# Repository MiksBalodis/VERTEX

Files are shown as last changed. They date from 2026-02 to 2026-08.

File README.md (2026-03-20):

# Aktīvās kontroles raķetes avionikas sistēma

## Projekta apraksts
Šis projekts paredz aktīvās kontroles raķetes avionikas sistēmas izstrādi, kas ietver gan raķetē iebūvētu avionikas datoru, gan zemes bāzi datu saņemšanai, uzglabāšanai un analīzei. Sistēma nodrošina aktīvu trajektorijas korekciju reāllaikā, izmantojot sensoru datus, vadības algoritmus un elektroniskos izpildmehānismus.

Projektā tiek apvienotas iegultās sistēmas, signālu apstrāde, vadības algoritmi, telemetrija un lietotāja saskarnes izstrāde.

**Projektu izstrādā:**  
Aleksandrs Jesiļevskis  
Miks Balodis  

---

## Projekta mērķis
Izstrādāt:
- raķetes avionikas datoru ar aktīvas trajektorijas korekcijas iespējām,
- zemes bāzi lidojuma datu saņemšanai un analīzei,
- drošu un papildināmu sistēmu, kas piemērota eksperimentālām lieljaudas raķetēm.

Sistēmai jāspēj:
- reāllaikā noteikt raķetes stāvokli,
- veikt aktīvo vadību ar vairākām kontroles spurām,
- ierakstīt un uzglabāt lidojuma datus,
- nodrošināt saziņu ar zemes bāzi lidojuma laikā.

---

## Idejas rašanās
Ideja radās, balstoties uz **RTU Lieljaudas raķeškomandas (RTU HPR)** 2025. gada 1. semestra projektu – aktīvās rotācijas kontroles raķeti. Šī projekta ietvaros tika izmantots RP2040 mikrokontrolieris, kuram konstatēti vairāki ierobežojumi:
- nav iebūvēta peldošā komata vienības (FPU),
- ierobežota programmas atmiņa,
- augsts enerģijas patēriņš.

Lai šos trūkumus novērstu, projektā tiek izvēlēts **STM32F405RGT6**, kas nodrošina augstāku veiktspēju, FPU atbalstu un DSP instrukcijas.

---

## Idejas apraksts

### Projekta lietotāji
- studentu raķešu komandas,
- augstskolu/vidusskolu eksperimentēšanas grupas,
- iegulto sistēmu un vadības algoritmu izstrādātāji,
- eksperimentālu raķešu un bezpilota sistēmu entuziasti.

### Izmantotās tehnoloģijas
- **Iegultās sistēmas:** STM32 (ARM Cortex-M4)
- **Sensori:** barometrs, IMU, GNSS
- **Vadības algoritmi:** PID, Kalmana filtrs
- **Telemetrija:** sub-GHz radio sakari
- **Programmatūra:** C/C++, MatLab/Simulink (simulācijas), JavaScript un Svelte (GUI)
- **Projektēšana:** KiCad

### Piegādes formāts
Projekta rezultāts būs:
- raķetes avionikas sistēmas plate (PCB),
- iegultā programmatūra gatava demonstratīvam raķetes lidojumam (firmware),
- zemes bāzes programmatūra (GUI),
- dokumentācija.

Šāda pieeja ļauj sistēmu izmantot gan eksperimentālos lidojumos, gan simulācijās.

---

## Aktīvā kontrole
Aktīvā kontrole ir vadības sistēma, kas lidojuma laikā nepārtraukti:
- mēra raķetes stāvokli (leņķi, ātrumu, rotāciju),
- aprēķina nepieciešamos labojumus,
- ģenerē PWM signālus izpildmehānismiem servo kontrolētām spurām.

Sistēma atbalsta līdz **4 aktīvām spurām**, katrai paredzot atsevišķu PWM kanālu. Salīdzinājumā ar pasīvo kontroli, aktīvā kontrole spēj reaģēt uz ārējiem traucējumiem un uzlabot stabilitāti un precizitāti.

---

## Risinājuma arhitektūra

### Konceptuālais modelis
Sistēma sastāv no trim galvenajiem blokiem:
1. **Sensoru slānis** – datu iegūšana
2. **Vadības un apstrādes slānis** – aprēķini un lēmumu pieņemšana
3. **Izpildes un komunikācijas slānis** – kontrole, datu uzglabāšana un pārraide

### Tehniskā arhitektūra

#### MCU
- **STM32F405RGT6** - mikrokontrolieris datu apstrādei un komandu nodošanai

#### Sensori
- **BMP388** – barometrs augstuma noteikšanai
- **LSM6DSO** – IMU (akselerometrs + žiroskops)
- **MAX-M10S** – GNSS modulis augstas precizitātes pozīcijai

#### Datu uzglabāšana
- **MXL1606** – lidojuma datu ierakstīšanai (USB Mass Storage režīms)
- **24LC64 EEPROM** – konfigurācijas datiem

#### Telemetrija
- **EBYTE E22-400M22S** - LoRa moudlis saziņai ar zemes bāzi (433 MHz)

#### Vadība
- PWM signāli spuru servo
- PID regulators
- Kalmana filtrs stāvokļa novērtēšanai

Projekta izstrādes Gantt diagramma
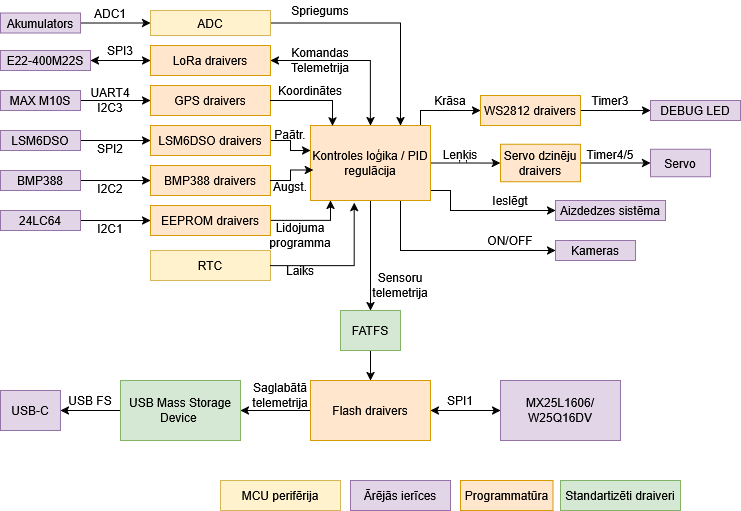
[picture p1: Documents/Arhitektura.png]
Projekta izstrādes Gantt diagramma

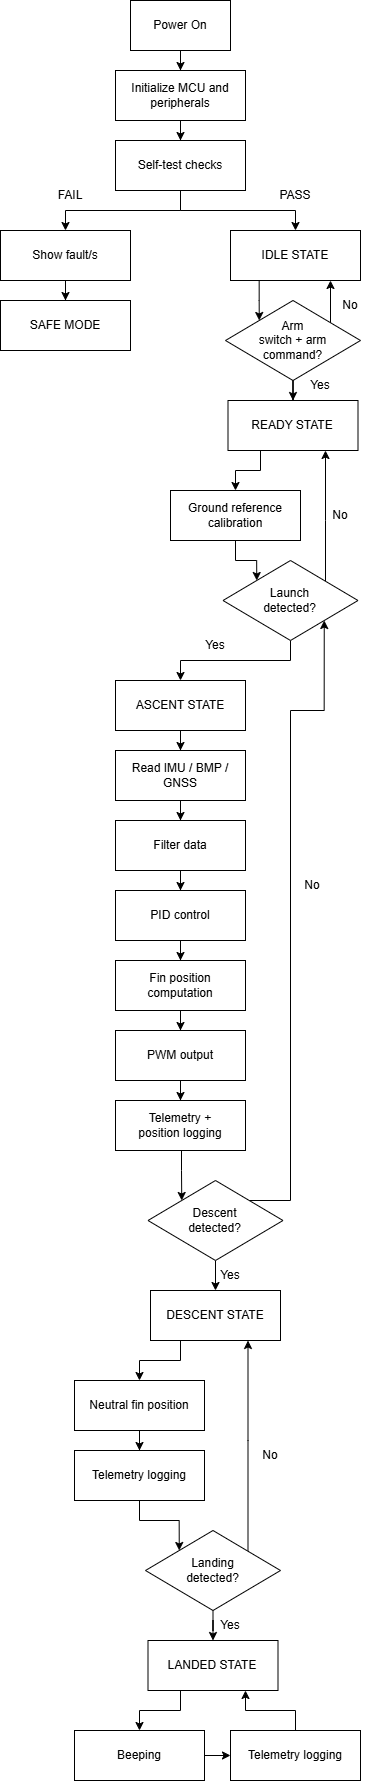
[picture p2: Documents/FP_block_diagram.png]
Flight computer block diagram


---
## Izstrādes plāns (10 nedēļas)

Projekta izstrāde ir plānota 10 nedēļu laikā, pieņemot, ka avionikas plate jau ir uzdizainēta un pasūtīta, un nākamais solis ir tās salodēšana. Darbs tiek sadalīts starp diviem izstrādātājiem, lai maksimāli efektīvi izmantotu paralēlu izstrādi.

### Lomu sadalījums
- **Aleksandrs** – iegultās sistēmas programmēšana, STM32 firmware, sensoru draiveri, datu plūsma, vadība un telemetrija, sistēmas arhitektūras lēmumi,  integrācija, testēšana un dokumentācija.
- **Miks** – raķetes tehniskā daļa, mehāniskā integrācija, Matlab/Simulink simulācijas, vadības algoritmu modelēšana un zemes stacijas aparatūra, sistēmas arhitektūras lēmumi,  integrācija, testēšana un dokumentācija.

---

### 1. nedēļa – Sistēmas inicializācija un modeļu sagatavošana
**Aleksandrs:**
- STM32CubeIDE projekta izveide
- Pulksteņu (clock tree) un pamata perifēriju konfigurācija
- Debug interfeisa (SWD/UART) inicializācija

**Miks:**
- Raķetes kustības konceptuālā modeļa izstrāde
- Aktīvās kontroles uzdevuma definēšana
- Sensoru mērījumu teorētisko modeļu izveide

**Rezultāts:**  
MCU veiksmīgi startē un sistēmas matemātiskais modelis ir definēts.

---

### 2. nedēļa – Perifēriju un datu plūsmas pamati
**Aleksandrs:**
- GPIO, UART, SPI un I2C konfigurācija
- DMA izmantošanas pamati datu pārsūtīšanai
- Vienkārša datu izvada testēšana

**Miks:**
- PID regulatora struktūras izveide Matlab/Simulink
- Sākotnējo vadības parametru novērtēšana
- Avionikas plates salodēšana

**Rezultāts:**  
MCU spēj komunicēt ar perifērijām, un PID struktūra ir gatava simulācijām, plate ir salodēta.

---

### 3. nedēļa – Avionikas plates salodēšana un sensoru testēšana
**Aleksandrs:**
- IMU (LSM6DSO) un barometra (BMP388) draiveru izstrāde
- Sensoru datu nolasīšana un izvadīšana caur UART

**Miks:**
- Barošanas un signālu līmeņu pārbaude
- Sensoru fiziskās integrācijas novērtēšana

**Rezultāts:**  
Pilnībā funkcionējoši aktīvie sensori.

---

### 4. nedēļa – GNSS un sensoru apvienošana
**Aleksandrs:**
- GNSS (MAX-M10S) draivera izstrāde
- Laika sinhronizācija starp sensoriem
- Datu struktūru definēšana

**Miks:**
- Sensoru kalibrācijas metodes
- Kļūdu modelēšana
- Mērījumu precizitātes izvērtēšana

**Rezultāts:**  
Apvienoti visi sensoru dati vienotā laika skalā.

---

### 5. nedēļa – Aktīvā vadība un izpildmehānismi
**Aleksandrs:**
- PWM izvades konfigurācija
- Taimeru konfigurācija izpildmehānismiem
- Izpildmehānismu testēšana

**Miks:**
- PID parametru regulēšana Simulink vidē
- Stabilitātes analīze
- Vadības algoritma validācija simulācijā

**Rezultāts:**  
Izpildmehānismi reaģē uz vadības signāliem paredzētajā veidā.

---

### 6. nedēļa – Datu apstrāde un uzglabāšana
**Aleksandrs:**
- USB Mass Storage režīma ieviešana
- Datu struktūras optimizācija

**Miks:**
- Kalmana filtra izstrāde Simulink vidē
- Algoritma sagatavošana ieviešanai C kodā

**Rezultāts:**  
Stabili ierakstīti un izgūstami lidojuma dati.

---

### 7. nedēļa – Telemetrija un zemes stacijas aparatūra
**Aleksandrs:**
- Telemetrijas protokola izstrāde
- EBYTE E22 radio moduļa integrācija
- Datu pakešu formāta definēšana

**Miks:**
- Zemes stacijas plates arhitektūras izstrāde
- Komponentu izvēle un shēmas dizains
- Komunikācijas interfeisa plānošana

**Rezultāts:**  
Bezvadu datu pārraide starp raķeti un zemes staciju.

---

### 8. nedēļa – Zemes stacijas programmatūra un GUI
**Aleksandrs:**
- Seriālās komunikācijas protokols ar datoru
- Telemetrijas datu parsēšana

**Miks:**
- Grafiskās lietotāja saskarnes izstrāde (Svelte)
- Reāllaika grafiki un datu attēlošana
- Datu eksportēšana analīzei

**Rezultāts:**  
Darbojoša zemes stacija ar reāllaika datu vizualizāciju.

---

### 9. nedēļa – Integrācija un sistēmas testi
**Aleksandrs:**
- Pilna vadības cikla integrācija
- Kļūdu apstrāde un drošības mehānismi

**Miks:**
- Vibrāciju testi
- Sensoru trokšņu ietekmes pārbaude

**Rezultāts:**  
Stabila un integrēta sistēma bez kritiskām kļūdām.

---

### 10. nedēļa – Stabilizācija un dokumentācija
**Abi:**
- Koda un aparatūras kļūdu labošana
- Projekta dokumentācijas pabeigšana
- Demonstrācijas sagatavošana

**Rezultāts:**  
Pilnībā sagatavots projekts demonstrācijai un prezentācijai.

---

## Projekta izstrādes grafiks

Projekta izstrādes Gantt diagramma

---

## Licence
Licence tiks noteikta projekta vēlākā izstrādes posmā.

---

## Kontakti
Jautājumu vai sadarbības gadījumā sazināties ar projekta izstrādātājiem.

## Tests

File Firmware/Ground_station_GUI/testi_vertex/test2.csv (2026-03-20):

time_ms | state | pitch | yaw | roll | altitude | speed | acceleration | error_flags | status_text
0 | IDLE | 0 | 0 | 0 | 0 | 0 | 0 | NONE | Systems safe. Awaiting command.
90 | IDLE | 0 | 0 | 0 | 0 | 0 | 0 | NONE | Systems safe. Awaiting command.
180 | IDLE | 0 | 0 | 0 | 0 | 0 | 0 | NONE | Systems safe. Awaiting command.
270 | IDLE | 0 | 0 | 0 | 0 | 0 | 0 | NONE | Systems safe. Awaiting command.
360 | IDLE | 0 | 0 | 0 | 0 | 0 | 0 | NONE | Systems safe. Awaiting command.
450 | IDLE | 0 | 0 | 0 | 0 | 0 | 0 | NONE | Systems safe. Awaiting command.
540 | IDLE | 0 | 0 | 0 | 0 | 0 | 0 | NONE | Systems safe. Awaiting command.
630 | IDLE | 0 | 0 | 0 | 0 | 0 | 0 | NONE | Systems safe. Awaiting command.
720 | IDLE | 0 | 0 | 0 | 0 | 0 | 0 | NONE | Systems safe. Awaiting command.
810 | IDLE | 0 | 0 | 0 | 0 | 0 | 0 | NONE | Systems safe. Awaiting command.
900 | SAFE | 0 | 0 | 0 | 0 | 0 | 0 | SELF_TEST_FAIL|IMU_FAIL | System fault detected. Safe mode active.
960 | SAFE | 0 | 0 | 0 | 0 | 0 | 0 | SELF_TEST_FAIL|IMU_FAIL | System fault detected. Safe mode active.
1020 | SAFE | 0 | 0 | 0 | 0 | 0 | 0 | SELF_TEST_FAIL|IMU_FAIL | System fault detected. Safe mode active.
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

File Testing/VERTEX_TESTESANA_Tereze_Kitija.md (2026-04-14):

# VERTEX projekta testēšana

RTU Inženierzinātņu vidusskolas  
11. klases skolnieces  
**Kitija Kampiņa** un **Terēze Luīze Kīne**  

---

# Funkcionālie testi

| Testa veids | Ievade, darbība | Sagaidāmais rezultāts | Patiesais rezultāts |
|---|---|---|---|
| CSV failu ielāde un testu palaišana | CSV failu ielāde un testu palaišana | CSV faili tiek veiksmīgi ielādēti un tests tiek palaists. | Strādā. CSV faili ielādējas un testēšana sākas. |
| Testu atkārtošana | Jauna vai tā paša CSV faila ielāde un atkārtota testēšana | Iespējams ielādēt jaunu failu un atkārtoti palaist testu ar to pašu vai citu CSV. | Daļēji strādā. Jaunu failu var ielādēt, bet atkārtota tā paša faila testēšana nedarbojas. Noderētu "Refresh" funkcija. |
| Normāls pilns lidojums | Pilna lidojuma scenārija simulācija | Stāvokļi mainās secīgi (IDLE → READY → ASCENT → DESCENT → LANDED), bez kļūdām rādījumi pieaug un pēc nosēšanās atgriežas uz nulli. | Strādā. Tiek veiksmīgi pārslēgti stāvokļi un netiek uzrādīta neviena kļūda. |
| Kļūda pirms lidojuma / SAFE režīms | Kļūdas aktivizēšana pirms lidojuma | Sistēma pāriet SAFE režīmā, lidojums nesākas, dati neizmainās. | Strādā. tiek uzrādītas SELF_TEST_FAIL un IMU_FAIL kļūdas. |
| Neatļauta stāvokļu pāreja | Nepareizas stāvokļu secības izsaukšana | Sistēma atpazīst nepareizu secību un uzrāda kļūdu. | Strādā. INVALID_STATE_TRANSITION kļūda tiek uzrādīta. |
| IMU datu zudums un atkopšanās | IMU datu zuduma simulācija | Parādās īslaicīgs datu zudums, pēc tam sistēma atkopjas, un lidojums beidzas veiksmīgi. | Strādā. IMU_DATA_LOST un IMU_RECOVERED tiek korekti uzrādīti. |
| Vairākas vienlaicīgas kļūdas | Vairāku kļūdu vienlaicīga aktivizēšana | Sistēma apstrādā vairākas kļūdas vienlaikus un turpina darbību. | Strādā. Nolaišanās laikā uzrāda GPS_LOST, BARO_FAIL un LOW_BATTERY kļūdu. Veiksmīga nosēšanās. |
| Sakaru zudums un GPS svārstības | Nestabilas sakaru un GPS darbības simulācija | Sistēma turpina darbību pēc īslaicīgas nestabilitātes. | Strādā. Lidojuma laikā tiek uzrādītas vairākas kļūdas, notiek atkopšanās un veiksmīga nosēšanās. |
| Stāvokļa pārejas kļūda ar atkopšanos | Kļūdas un atkopšanās scenārijs | Sistēma konstatē kļūdu un pēc tam atkopjas. | Strādā. Uzrāda INVALID_STATE_TRANSITION kļūdu, notiek atkopšanās un veiksmīga nosēšanās. |
| Jaukts anomāliju tests | Kombinēts kļūdu scenārijs | Sistēma apstrādā vairākas kļūdas bez darbības pārtraukuma. | Strādā. Lidojuma laikā parādās daudz kļūdas paziņojumu, notiek atkopšanās un veiksmīga nosēšanās. |

---

# Nefunkcionālie testi

| Testa veids | Ievade, darbība | Sagaidāmais rezultāts | Patiesais rezultāts |
|---|---|---|---|
| Atvēršana no citiem datoriem | Sistēmas atvēršana no cita datora tīklā | Sistēma ir pieejama tīklā un darbojas citos datoros. | Strādā. Sistēmu var atvērt no citiem datoriem. |
| Atvēršana no mobilajām ierīcēm | Sistēmas atvēršana mobilajā ierīcē | Sistēma darbojas mobilajās ierīcēs ar pielāgotu UI. | Nestrādā. aplikācija nav optimizēta mobilajām ierīcēm. |
| Sākumlapas pieejamība | Viena HTTP pieprasījuma nosūtīšana | Sistēma atbild uz pieprasījumu bez kļūdām. | Tika nosūtīts viens HTTP pieprasījums, kas tika apstrādāts veiksmīgi (100% OK, 0% kļūdu). Atbildes laiks bija 340 ms, kas norāda uz pieņemamu reakcijas ātrumu. Tomēr, ņemot vērā, ka tests ietvēra tikai vienu pieprasījumu, nav iespējams izdarīt secinājumus par sistēmas veiktspēju vai stabilitāti pie lielākas slodzes. Šis tests kalpo kā sākotnējais sistēmas pieejamības pārbaudījums (smoke test). |
| Vienmērīga lietotāju slodze | 300 HTTP pieprasījumu nosūtīšana | Sistēma uztur stabilu veiktspēju pie nemainīgas slodzes. | Tika nosūtīti 300 HTTP pieprasījumi, no kuriem visi tika apstrādāti veiksmīgi (100% OK, 0% kļūdu). Vidējais atbildes laiks bija 29 ms, savukārt 95% pieprasījumu tika apstrādāti ātrāk par 66 ms, kas norāda uz ļoti labu sistēmas veiktspēju. Lai gan maksimālais atbildes laiks sasniedza 557 ms, šādi gadījumi bija reti un neietekmē kopējo sistēmas darbību. Rezultāti liecina, ka sistēma ir stabila un spēj efektīvi apkalpot lietotājus pie dotās slodzes. |
| Pieaugoša slodze (Ramp-up) | Pakāpeniski pieaugoša pieprasījumu plūsma | Sistēma saglabā veiktspēju pie pakāpeniskas slodzes pieauguma. | Tika simulēts pakāpeniski pieaugošs lietotāju skaits, nosūtot 100 HTTP pieprasījumus 58 sekunžu laikā. Visi pieprasījumi tika apstrādāti veiksmīgi (100% OK, bez kļūdām). Vidējais atbildes laiks bija 18 ms, savukārt 95% pieprasījumu tika apstrādāti ātrāk par 26 ms, kas liecina par ļoti labu sistēmas veiktspēju arī pie pieaugošas slodzes. Maksimālais atbildes laiks sasniedza 175 ms, tomēr šādi gadījumi bija reti un neietekmēja kopējo sistēmas darbību. Rezultāti norāda, ka sistēma spēj stabili un efektīvi apkalpot lietotājus pie pakāpeniski pieaugošas slodzes bez būtiskas veiktspējas degradācijas. |
| Ilgstoša slodze (Soak test) | Ilgstoša slodze ar 1500 pieprasījumiem | Sistēma ilgstoši darbojas bez veiktspējas pasliktināšanās. | Tika simulēta ilgstoša, nemainīga slodze 5 minūšu laikā, nosūtot 1500 HTTP pieprasījumus. Visi pieprasījumi tika apstrādāti veiksmīgi (100% OK, bez kļūdām). Vidējais atbildes laiks bija 14 ms, savukārt 95% pieprasījumu tika apstrādāti ātrāk par 20 ms, kas norāda uz ļoti stabilu sistēmas darbību ilgstošas slodzes apstākļos. Maksimālais atbildes laiks sasniedza 198 ms, tomēr šādi gadījumi bija reti un neietekmēja kopējo sistēmas veiktspēju. Testa rezultāti neuzrādīja būtisku veiktspējas degradāciju laika gaitā, kas liecina par sistēmas stabilitāti un spēju uzturēt nemainīgu darbību ilgstošas slodzes apstākļos. |
| Pīķa slodze (Spike test) | Straujš pieprasījumu pieaugums (200 vienlaikus) | Sistēma saglabā darbību pie strauja slodzes pieauguma. | Pīķa slodzes testā tika simulēts straujš lietotāju skaita pieaugums, vienlaikus nosūtot 200 pieprasījumus. Visi pieprasījumi tika apstrādāti veiksmīgi (100% OK, bez kļūdām), kas liecina par sistēmas stabilitāti pat pie augstas slodzes. Tomēr vidējais atbildes laiks būtiski palielinājās līdz 1115 ms, un lielākā daļa pieprasījumu tika apstrādāti 800–1200 ms intervālā. Tas norāda, ka sistēma nespēj uzturēt augstu veiktspēju pie pēkšņas slodzes pieauguma, lai gan tā saglabā funkcionalitāti. Rezultāti liecina, ka sistēma ir stabila, bet ne optimizēta darbam pīķa slodzes apstākļos. |
| Statisko resursu tests | Statisko resursu pieprasījumu nosūtīšana | Visi resursi (HTML, CSS, attēli) ielādējas korekti. | Statisko resursu testā tika pārbaudīta sākumlapas, CSS un favicon ielāde, kopumā nosūtot 150 HTTP pieprasījumus. Visi pieprasījumi tika apstrādāti veiksmīgi (100% OK, bez kļūdām). Vidējais atbildes laiks bija 30 ms, un 95% pieprasījumu tika apstrādāti ātrāk par 34 ms, kas liecina par labu sistēmas veiktspēju statisko resursu piegādē. Tomēr tika novēroti atsevišķi gadījumi ar augstāku atbildes laiku (līdz 1293 ms), kas var būt saistīti ar kešošanas neizmantošanu vai pirmreizēju resursu ielādi. Kopumā sistēma spēj efektīvi piegādāt statiskos resursus, nodrošinot ātru lietotāja pieredzi. |

## Šeit pieejams kods izstrādātajām Gatling simulācijām, kas tika izmantotas, lai testētu sistēmas slodzes panesamību: [VERTEX simulācijas](TESTESANA-AR-GATLING)

---

# Integrācijas testi

## 1. tests: Pārbaudīt, vai CSV ielādes modulis korekti nodod datus parserim un parseris korekti nodod tos GUI attēlošanai.
Ievade / darbība: Tiek ielādēts CSV fails ar šādu saturu:
time,ax,ay,az,altitude
  0.0,0.01,0.02,9.81,0.0  
  0.1,0.03,0.01,9.84,0.5  
  0.2,0.10,0.05,10.20,2.0  
  0.3,0.20,0.07,11.30,5.5  
  0.4,0.15,0.04,10.80,8.0  
  
**Sagaidāmais rezultāts:** CSV fails tiek nolasīts, parseris korekti sadala laukus, un GUI grafikos tiek attēlotas atbilstošās ax, ay, az un altitude vērtības bez kļūdām.  
**Rezultāts:** dati tiek korekti attēloti GUI.
  
---
## 2. tests: Pārbaudīt, vai telemetrijas datu plūsma no “fake source” tiek korekti apstrādāta un reāllaikā atjauno GUI grafikus.
Ievade / darbība: Tiek izmantots datu avots, kas periodiski sūta šādas rindas:
  0.0,0.12,-0.05,9.79,0.0  
  0.1,0.08,0.02,9.85,0.3  
  0.2,0.15,0.01,10.10,1.1  
  0.3,0.30,0.10,11.00,3.8  
  0.4,0.25,0.04,10.60,6.4  
  
**Sagaidāmais rezultāts:** GUI saņem jaunos datus, grafiki mainās katrā jaunajā solī un programma neuzkaras.  
**Rezultāts:** Grafiki tiek atjaunināti, un GUI saglabā darbspēju.
  
---
## 3. tests: Pārbaudīt, vai parseris un GUI korekti apstrādā nepareizā secībā saņemtus telemetrijas ierakstus.
Ievade / darbība: Tiek padoti šādi dati sajauktā secībā:
time,ax,ay,az,altitude  
 0.3,0.20,0.07,11.30,5.5  
 0.1,0.03,0.01,9.84,0.5  
 0.4,0.15,0.04,10.80,8.0  
 0.0,0.01,0.02,9.81,0.0  
 0.2,0.10,0.05,10.20,2.0  
  
**Sagaidāmais rezultāts:** Sistēma vai nu sakārto ierakstus pēc time lauka, vai ignorē nekorekti pienākušos punktus, bet GUI neuzkaras un neattēlo acīmredzami bojātu grafiku.  
**Rezultāts:** GUI un parsera savienojums saglabā darbspēju arī pie sajauktas secības datiem.
  
---
## 4. tests: Pārbaudīt, vai parseris un GUI korekti apstrādā rindas ar trūkstošiem datu laukiem.
Ievade / darbība: Tiek ielādēts CSV fails ar trūkstošu ay vērtību vienā ierakstā:
time,ax,ay,az,altitude  
 0.0,0.01,0.02,9.81,0.0  
 0.1,0.03,0.01,9.84,0.5  
 0.2,0.10,,10.20,2.0  
 0.3,0.20,0.07,11.30,5.5  
 0.4,0.15,0.04,10.80,8.0  
  
**Sagaidāmais rezultāts:** Parseris neatstāj sistēmu nekorektā stāvoklī, GUI necrasho, un trūkstošā vērtība tiek vai nu atzīmēta kā null, vai arī konkrētais punkts netiek attēlots.  
**Rezultāts:** Nepilnīgie dati neizraisa programmas avāriju, un GUI turpina darboties.
  
---
## 5. tests: Pārbaudīt, vai lielas datu plūsmas gadījumā parseris, datu glabāšana atmiņā un GUI grafiku atjaunošana darbojas kopā bez kritiskas aiztures.
Ievade / darbība: Tiek padota augstas intensitātes datu plūsma, piemēram:
time,ax,ay,az,altitude  
 0.00,0.10,0.02,9.80,0.0  
 0.01,0.11,0.03,9.82,0.1  
 0.02,0.12,0.02,9.85,0.3  
 0.03,0.18,0.04,10.10,0.7  
 0.04,0.22,0.06,10.80,1.4  
 ...  
 9.99,-0.05,0.01,9.70,0.0  
  
**Sagaidāmais rezultāts:** Datu plūsma tiek apstrādāta, GUI paliek lietojams, grafiki tiek atjaunoti un programma nekrīt pat pie ievērojami lielāka datu apjoma.  
**Rezultāts:** Sistēma apstrādā lielāku datu apjomu bez kritiskas kļūmes.
  
---
## 6. tests: Pārbaudīt, vai sensoru datu apvienošanas modulis korekti sadarbojas ar GUI stāvokļa attēlojumu.
Ievade / darbība: Tiek padoti sintētiski IMU un GNSS dati lineārai kustībai:
time,ax,ay,az,gnss_x,gnss_y,gnss_z  
 0.0,0.00,0.00,9.81,0.0,0.0,0.0  
 0.1,0.20,0.00,9.81,0.5,0.0,0.0  
 0.2,0.20,0.00,9.81,1.0,0.0,0.0  
 0.3,0.20,0.00,9.81,1.5,0.0,0.0  
 0.4,0.20,0.00,9.81,2.0,0.0,0.0  
  
**Sagaidāmais rezultāts:** Sensoru apvienošanas modulis aprēķina stabilu stāvokļa novērtējumu, un GUI šo novērtējumu attēlo bez lēcieniem, kļūdām vai datu sabrukuma.  
**Rezultāts:** Datu apvienošanas rezultāts tiek korekti nodots GUI attēlošanai.

---
# Secinājumi un ieteikumi

## Secinājumi

Programmas testēšanas rezultāti parāda, ka VERTEX sistēma kopumā darbojas korekti un izpilda tai paredzētās pamatfunkcijas. Funkcionālie testi apliecina, ka sistēma spēj ielādēt CSV failus, korekti attēlot lidojuma stāvokļus un apstrādāt dažādus kļūdu scenārijus, nodrošinot arī veiksmīgu atkopšanos.

Nefunkcionālo testu rezultāti liecina, ka sistēma ir stabila pie normālas, pakāpeniski pieaugošas un ilgstošas slodzes. Tiek uzturēts zems atbildes laiks un netiek novērotas kļūmes. Tomēr pīķa slodzes apstākļos novērojama būtiska veiktspējas pasliktināšanās, kas norāda, ka sistēma saglabā funkcionalitāti, bet nav pilnībā optimizēta straujam lietotāju pieaugumam.

Integrācijas testi apstiprina, ka galvenie sistēmas moduļi – CSV ielāde, datu parsēšana un GUI attēlošana – savstarpēji darbojas korekti arī nestandarta situācijās. Sistēma saglabā stabilitāti pie nepilnīgiem datiem, sajauktas secības un lielākas datu plūsmas.

Kopumā sistēma ir funkcionāli pilnvērtīga un stabila, ar labu pamatu turpmākai attīstībai.

## Ieteikumi

- Ieteicams ieviest iespēju atkārtoti palaist testu ar to pašu CSV failu bez lapas pārlādes, piemēram, pievienojot Refresh vai Reset funkciju. Tas būtiski uzlabotu lietojamību.

- Nepieciešams optimizēt sistēmas darbību pīķa slodzes apstākļos, lai samazinātu atbildes laiku pie strauja lietotāju skaita pieauguma.

- Būtu vēlams uzlabot statisko resursu ielādi, ieviešot "cache" mehānismus un optimizējot pirmreizējo ielādi.

- Ieteicams apsvērt responsīva dizaina ieviešanu, ja nākotnē plānota sistēmas izmantošana mobilajās ierīcēs.

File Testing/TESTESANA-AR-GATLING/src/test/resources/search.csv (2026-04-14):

searchCriterion | searchComputerName
Macbook | MacBook Pro
eee | ASUS Eee PC 1005PE

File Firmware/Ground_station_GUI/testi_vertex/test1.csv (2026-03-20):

time_ms | state | pitch | yaw | roll | altitude | speed | acceleration | error_flags | status_text
0 | IDLE | 0 | 0 | 0 | 0 | 0 | 0 | NONE | Systems safe. Awaiting command.
90 | IDLE | 0 | 0 | 0 | 0 | 0 | 0 | NONE | Systems safe. Awaiting command.
180 | IDLE | 0 | 0 | 0 | 0 | 0 | 0 | NONE | Systems safe. Awaiting command.
270 | IDLE | 0 | 0 | 0 | 0 | 0 | 0 | NONE | Systems safe. Awaiting command.
360 | IDLE | 0 | 0 | 0 | 0 | 0 | 0 | NONE | Systems safe. Awaiting command.
450 | IDLE | 0 | 0 | 0 | 0 | 0 | 0 | NONE | Systems safe. Awaiting command.
540 | IDLE | 0 | 0 | 0 | 0 | 0 | 0 | NONE | Systems safe. Awaiting command.
630 | IDLE | 0 | 0 | 0 | 0 | 0 | 0 | NONE | Systems safe. Awaiting command.
720 | IDLE | 0 | 0 | 0 | 0 | 0 | 0 | NONE | Systems safe. Awaiting command.
810 | IDLE | 0 | 0 | 0 | 0 | 0 | 0 | NONE | Systems safe. Awaiting command.
900 | IDLE | 0 | 0 | 0 | 0 | 0 | 0 | NONE | Systems safe. Awaiting command.
990 | IDLE | 0 | 0 | 0 | 0 | 0 | 0 | NONE | Systems safe. Awaiting command.
1080 | IDLE | 0 | 0 | 0 | 0 | 0 | 0 | NONE | Systems safe. Awaiting command.
1170 | IDLE | 0 | 0 | 0 | 0 | 0 | 0 | NONE | Systems safe. Awaiting command.
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

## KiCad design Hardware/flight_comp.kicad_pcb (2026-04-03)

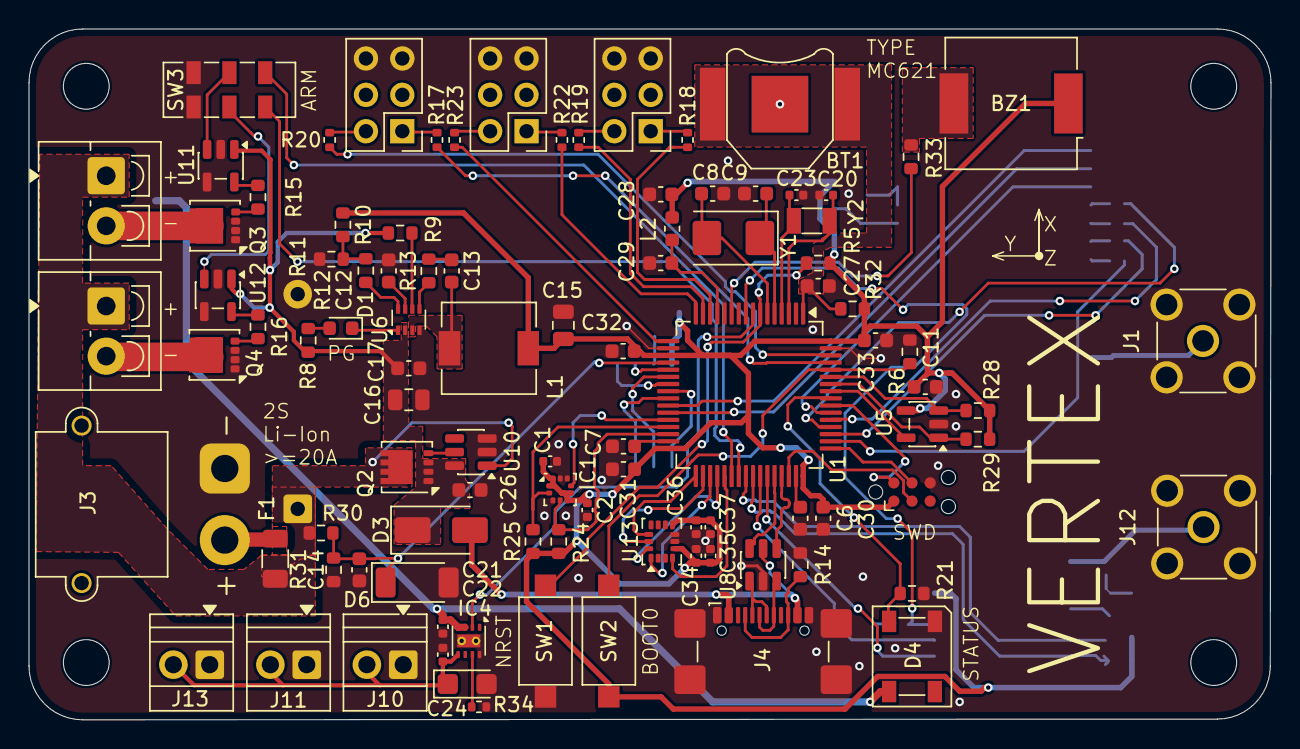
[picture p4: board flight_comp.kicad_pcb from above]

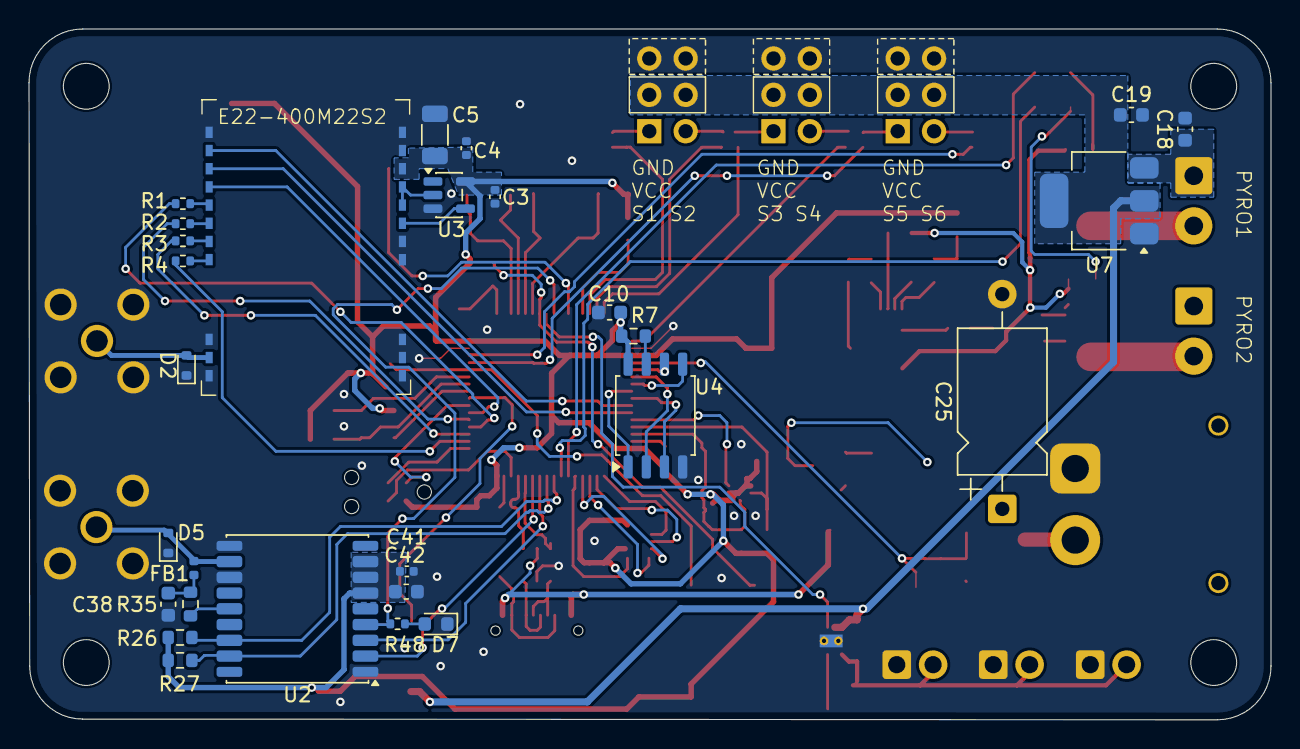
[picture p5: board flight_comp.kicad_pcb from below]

Board: 4 copper layers, 86.7 x 48.2 mm, 129 parts (28 on the bottom side), 104 nets.

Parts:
BT1: MC621; BatteryHolder_Keystone_2998_1x6.8mm
BZ1: Buzzer; Buzzer_CUI_CPT-9019S-SMT
C1, C2, C3, C34, C37, C41: 100nF; C_0402_1005Metric
C4: 10µF; C_0402_1005Metric
C5: 47 µF; C_1206_3216Metric
C6, C7: 2.2uF; C_0603_1608Metric
C8, C9: 22pF; C_0603_1608Metric
C10, C11, C14, C26, C27, C28, C29, C30, C31, C32, C33: 0.1uF; C_0603_1608Metric
C12: 6.8nF; C_0603_1608Metric
C13: 1uF; C_0603_1608Metric
C15: 44uF; C_0805_2012Metric
C16: 22uF; C_0805_2012Metric
C17: 100nF; C_0603_1608Metric
C18, C42: 10uF; C_0603_1608Metric
C19: 22uF; C_0603_1608Metric
C20, C23: 22pF; C_0402_1005Metric
C21, C22: 0.1uF; C_0402_1005Metric
C24: 6TPF470MFH; CP_EIA-3216-10_Kemet-I
C25: 1000uF; CP_Axial_L10.0mm_D6.0mm_P15.00mm_Horizontal
C35, C36: 10uF; C_0402_1005Metric
C38: 10nF; C_0603_1608Metric
D1, D7: LED; LED_0603_1608Metric
D2, D5: D_TVS; D_SOD-523
D3: SS24; D_SMA
D4: SK6812; LED_SK6812_PLCC4_5.0x5.0mm_P3.2mm
D6: 3.6V; D_SOD-128
E22-400M22S2: E22-400M22S
F1: Fuse; Fuse_1206_3216Metric
FB1: LQG15HS27NH02D; L_0402_1005Metric
H1, H2, H3, H4: MountingHole; MountingHole_3.2mm_M3
IC1: BMP388; ST_HLGA-10_2x2mm_P0.5mm_LayoutBorder3x2y
IC4: TPS259531DSGR; WSON-8-1EP_2x2mm_P0.5mm_EP0.9x1.6mm_ThermalVias
J1, J12: Conn_Coaxial; SMA_Molex_73251-2200_Horizontal
J2: TC2030; Tag-Connect_TC2030-IDC-NL_2x03_P1.27mm_Vertical
J3: XT30; AMASS_XT30PW-M_1x02_P2.50mm_Horizontal
J4: USB_C_Receptacle_USB2.0_16P; USB_C_Receptacle_GCT_USB4110
J5, J6: Conn_01x02; TerminalBlock_4Ucon_1x02_P3.50mm_Vertical
J7: SERVO_CONN_01; PinHeader_2x03_P2.54mm_Vertical
J8, J9: SERVO_CONN_02; PinHeader_2x03_P2.54mm_Vertical
J10: CAMERA_CONN_01; TerminalBlock_Xinya_XY308-2.54-2P_1x02_P2.54mm_Horizontal
J11: CAMERA_CONN_02; TerminalBlock_Xinya_XY308-2.54-2P_1x02_P2.54mm_Horizontal
J13: CAMERA_CONN_03; TerminalBlock_Xinya_XY308-2.54-2P_1x02_P2.54mm_Horizontal
L1: 2.2uH; L_6.3x6.3_H3
L2: L; L_0603_1608Metric
Q2: DMP3013SFV; Diodes_PowerDI3333-8
Q3, Q4: CSD17577Q3A; VSON-8_3.3x3.3mm_P0.65mm_NexFET
R1, R2, R3, R4: 100Ω; R_0402_1005Metric
R5, R6, R7, R21: 10k; R_0603_1608Metric
R8, R33: 1k; R_0603_1608Metric
R9: 604k; R_0603_1608Metric
R10: 40.2k; R_0603_1608Metric
R11: 13k; R_0603_1608Metric
R12: 20k; R_0603_1608Metric
R13: 20R; R_0603_1608Metric
R14: 4.7k; R_0603_1608Metric
R15, R16: 22R; R_0603_1608Metric
R17, R18, R19, R20, R22, R23: 100; R_0402_1005Metric
R24, R25, R26, R27, R28, R29, R30, R31: R; R_0603_1608Metric
R32: 0R; R_0603_1608Metric
R34: 5k; R_0402_1005Metric
R35: 10; R_0603_1608Metric
R48: 220Ω; R_0402_1005Metric
SW1: NRST; SW_SPST_CK_RS282G05A3
SW2: BOOT0; SW_SPST_CK_RS282G05A3
SW3: EG2219; SW_DPDT_CK_JS202011JCQN
U1: STM32F405RGTx; LQFP-64_10x10mm_P0.5mm
U2: MAX-M10S; ublox_MAX
U3: 74LVC1GU04; SOT-23-5
U4: W25Q32JVSS; SOIC-8_5.3x5.3mm_P1.27mm
U5: 24LC64; SOT-23-5
U6: MP2331; SOT-583-8
U7: AMS1117-5.0; SOT-223-3_TabPin2
U8: USBLC6-2SC6; SOT-23-6
U10: LTC4412; TSOT-23-6
U11, U12: UCC27517A; SOT-23-5
U13: LSM6DSO; LGA-14_3x2.5mm_P0.5mm_LayoutBorder3x4y
Y1: 8mHz; Crystal_SMD_5032-2Pin_5.0x3.2mm
Y2: 32.768 kHz; Crystal_SMD_3215-2Pin_3.2x1.5mm

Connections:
+3.3V: BZ1.1 (+), C1.2, C2.2, C3.2, C4.2, C5.2, C10.1, C11.1, C15.1, C28.1, C30.1, C31.1, C32.1, C33.1, C34.2, C35.2, C36.2, C37.1, C41.1, C42.1, E22-400M22S2.9 (VCC), IC1.1 (VDDIO), IC1.5 (SDO), IC1.6 (CSB), IC1.10 (VDD), J2.1, L1.2, L2.1, R5.2, R7.2, R10.1, R24.1, R25.1, R26.1, R27.1, R28.1, R29.1, R32.2, SW2.1, U1.19 (VDD), U1.32 (VDD), U1.48 (VDD), U1.64 (VDD), U2.6 (V_BCKP), U2.7 (VCC_IO), U2.8 (VCC), U3.5 (VCC), U4.8 (VCC), U5.4 (VCC), U13.5 (VDDIO), U13.8 (VDD)
+3.3VA: C29.1, L2.2, U1.13 (VDDA)
+3.3VB: BT1.1 (+), C27.1, R32.1, U1.1 (VBAT)
+5V: C19.1, C21.1, D4.3 (VDD), IC4.3 (IN_1), IC4.4 (IN_2), J7.3, J7.4, J8.3, J8.4, J9.3, J9.4, U7.2 (VO)
+BATT: C18.1, C25.1, F1.2, J5.1, J6.1, Q2.5 (D), R30.1, U7.3 (VI), U10.1 (VIN)
/SENSORS/RXEN: E22-400M22S2.6 (RXEN), U3.4
/SENSORS/TXEN: E22-400M22S2.7 (TXEN), E22-400M22S2.8 (DIO2), U3.2
BAT_VSENCE: C14.1, D6.1 (K), R30.2, R31.1, U1.20 (PA4)
BMP_INT: IC1.7 (INT), U1.28 (PB2)
BMP_SCL: IC1.2 (SCK), R25.2, U1.29 (PB10)
BMP_SDA: IC1.4 (SDI), R24.2, U1.30 (PB11)
BUZZ: R33.1, U1.11 (PC3)
CAMERA_SWITCH: IC4.2 (EN/UVLO), U1.8 (PC0)
EEP_SCL: R29.2, U1.58 (PB6), U5.1 (SCL)
EEP_SDA: R28.2, U1.59 (PB7), U5.3 (SDA)
EEP_WP: U1.57 (PB5), U5.5 (WP)
FLASH_CS: U1.24 (PC4), U4.1 (~CS)
FLASH_MISO: U1.22 (PA6), U4.2 (DO/IO_{1})
FLASH_MOSI: U1.23 (PA7), U4.5 (DI/IO_{0})
FLASH_SCK: U1.21 (PA5), U4.6 (CLK)
FLASH_WP: U1.25 (PC5), U4.3 (~WP/IO_{2})
GND: BT1.2 (-), C1.1, C2.1, C3.1, C4.1, C5.1, C6.2, C7.2, C8.2, C9.2, C10.2, C11.2, C12.2, C14.2, C15.2, C16.2, C17.2, C18.2, C19.2, C20.2, C21.2, C22.2, C23.2, C24.2 (-), C25.2, C26.2, C27.2, C28.2, C29.2, C30.2, C31.2, C32.2, C33.2, C34.1, C35.1, C36.1, C37.2, C38.2, C41.2, C42.2, D2.1 (A1), D4.1 (VSS), D5.1 (A1), D6.2 (A), D7.1 (K), E22-400M22S2.1 (GND), E22-400M22S2.2 (GND), E22-400M22S2.3 (GND), E22-400M22S2.4 (GND), E22-400M22S2.5 (GND), E22-400M22S2.10 (GND), E22-400M22S2.11 (GND), E22-400M22S2.12 (GND), E22-400M22S2.20 (GND), E22-400M22S2.22 (GND), IC1.3 (VSS_1), IC1.8 (VSS_2), IC1.9 (VSS_3), IC4.8 (GND_1), IC4.9 (GND_2), J1.2 (Ext), J2.6, J3.1, J4.A1 (GND), J4.A12 (GND), J4.B1 (GND), J4.B12 (GND), J4.S1 (SHIELD), J7.5, J7.6, J8.5, J8.6, J9.5, J9.6, J10.1, J11.1, J12.2 (Ext), J13.1, Q3.1 (S), Q3.2 (S), Q3.3 (S), Q4.1 (S), Q4.2 (S), Q4.3 (S), R6.1, R11.2, R14.2, R21.2, R31.2, R34.2, SW1.1, SW3.1 (A), SW3.4 (A), U1.12 (VSSA), U1.18 (VSS), U1.63 (VSS), U2.1 (GND), U2.10 (GND), U2.12 (GND), U3.3 (GND), U4.4 (GND), U5.2 (GND), U6.4 (GND), U7.1 (GND), U8.2 (GND), U10.2 (GND), U10.3 (CTL), U11.2 (GND), U11.4 (IN-), U12.2 (GND), U12.4 (IN-), U13.6 (GND@6), U13.7 (GND@7)
GPS_RX: U1.43 (PA10), U2.2 (TXD)
GPS_SCL: R27.2, U1.41 (PA8), U2.17 (SCL)
GPS_SDA: R26.2, U1.40 (PC9), U2.16 (SDA)
GPS_TX: U1.42 (PA9), U2.3 (RXD)
IMU_CS: U1.33 (PB12), U13.12 (~CS)
IMU_INT1: U1.37 (PC6), U13.4 (INT1)
IMU_MISO: U1.35 (PB14), U13.1 (SDO/SA0)
IMU_MOSI: U1.36 (PB15), U13.14 (SDA)
IMU_SCK: U1.34 (PB13), U13.13 (SCL)
LED: D4.2 (DIN), R21.1, U1.56 (PB4)
LORA_CS: R4.1, U1.50 (PA15)
LORA_DIO1: E22-400M22S2.13 (DIO1), U1.26 (PB0)
LORA_IO0: E22-400M22S2.14 (BUSY), U1.27 (PB1)
LORA_MISO: R1.1, U1.52 (PC11)
LORA_MOSI: R2.1, U1.53 (PC12)
LORA_NRST: E22-400M22S2.15 (NRST), U1.54 (PD2)
LORA_SCK: R3.1, U1.51 (PC10)
unnamed: BZ1.2 (-), R33.2
unnamed: C13.1, R13.2
unnamed: C22.1, C24.1 (+), IC4.5 (OUT), J10.2, J11.2, J13.2
unnamed: C38.1, FB1.1, R35.2
unnamed: D1.2 (A), R8.2
unnamed: D1.1 (K), U6.1 (PG)
unnamed: D2.2 (A2), E22-400M22S2.21 (ANT), J1.1 (In)
unnamed: D5.2 (A2), FB1.2, J12.1 (In), U2.11 (RF_IN)
unnamed: D7.2 (A), R48.1
unnamed: E22-400M22S2.16 (MISO), R1.2
unnamed: E22-400M22S2.17 (MOSI), R2.2
unnamed: E22-400M22S2.19 (NSS), R4.2
unnamed: E22-400M22S2.18 (SCK), R3.2
unnamed: IC4.7 (ILM), R34.1
unnamed: F1.1, J3.2
unnamed: J4.A5 (CC1), J4.B5 (CC2), R14.1
unnamed: J4.A6 (D+), J4.B6 (D+), U8.3 (I/O2)
unnamed: J4.A7 (D-), J4.B7 (D-), U8.1 (I/O1)
unnamed: J5.2, Q3.5 (D)
unnamed: J6.2, Q4.5 (D)
unnamed: J7.1, R18.2
unnamed: J7.2, R19.1
unnamed: J8.1, R22.2
unnamed: J8.2, R23.1
unnamed: J9.1, R17.2
unnamed: J9.2, R20.1
unnamed: Q2.4 (G), U10.5 (GATE)
unnamed: Q3.4 (G), R15.2
unnamed: Q4.4 (G), R16.2
unnamed: R10.2, R11.1, R12.2
unnamed: SW3.2 (B), U11.3 (IN+)
unnamed: SW3.5 (B), U12.3 (IN+)
unnamed: R6.2, SW2.2, U1.60 (BOOT0)
unnamed: R5.1, SW1.2, U1.7 (NRST)
unnamed: C7.1, U1.31 (VCAP_1)
unnamed: C6.1, U1.47 (VCAP_2)
unnamed: R35.1, U2.14 (VCC_RF)
unnamed: R7.1, U4.7 (~HOLD/~RESET/IO_{3})
unnamed: R13.1, U6.5 (BST)
unnamed: R9.2, U6.6 (EN)
unnamed: R12.1, U6.8 (FB)
unnamed: C12.1, U6.7 (SS)
unnamed: C13.2, L1.1, U6.3 (SW)
unnamed: R15.1, U11.5 (OUT)
unnamed: R16.1, U12.5 (OUT)
OSC32_IN: C20.1, U1.3 (PC14), Y2.1
OSC32_OUT: C23.1, U1.4 (PC15), Y2.2
OSC_IN: C9.1, U1.5 (PH0), Y1.1
OSC_OUT: C8.1, U1.6 (PH1), Y1.2
PPS: R48.2, U1.9 (PC1), U2.4 (TIMEPULSE)
PYRO_1: SW3.3 (C), U1.38 (PC7)
PYRO_2: SW3.6 (C), U1.39 (PC8)
SYS_SWCLK: J2.4, U1.49 (PA14)
SYS_SWDIO: J2.3, U1.46 (PA13)
SYS_SWO: J2.2, U1.55 (PB3)
TIM4_CH3: R17.1, U1.61 (PB8)
TIM4_CH4: R20.2, U1.62 (PB9)
TIM5_CH1: R18.1, U1.14 (PA0)
TIM5_CH2: R19.2, U1.15 (PA1)
TIM5_CH3: R22.1, U1.16 (PA2)
TIM5_CH4: R23.2, U1.17 (PA3)
USB_DN: U1.44 (PA11), U8.6 (I/O1)
USB_DP: U1.45 (PA12), U8.4 (I/O2)
VBUS: D3.2 (A), J4.A4 (VBUS), J4.A9 (VBUS), J4.B4 (VBUS), J4.B9 (VBUS), U8.5 (VBUS)
VCC: C16.1, C17.1, C26.1, D3.1 (K), Q2.1 (S), Q2.2 (S), Q2.3 (S), R8.1, R9.1, U6.2 (VIN), U10.6 (SENSE), U11.1 (V_{DD}), U12.1 (V_{DD})

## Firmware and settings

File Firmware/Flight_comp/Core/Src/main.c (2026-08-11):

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
/* Includes ------------------------------------------------------------------*/
#include "main.h"
#include "fatfs.h"
#include "usb_device.h"

/* USER CODE BEGIN Includes */
#include "25flash.h"
#include "neopixel.h"
#include "buzzer.h"
#include "lsm6dso.h"
#include "BMP388.h"
#include "ee24.h"
#include "servo.h"
#include "gps.h"
#include "SX1262.h"
#include "imu_fusion.h"
#include "mission.h"
#include <string.h>
#include "stdbool.h"
#include "tvc_servo.h"
/* USER CODE END Includes */

/* USER CODE BEGIN PD */
/* ===========================================================================
   BENCH SERVO TEST — remove/comment out before flight.
   When defined, main() runs Servo_BenchTest() forever right after the servos
   are initialised, and never proceeds to the mission. It sweeps each TVC servo
   on its own (servo 1 first, then servo 2) between home+20 and home-20 deg,
   pausing at each end so you can watch whether it actually reaches the position.
   Purely a mechanical/wiring check; comment the line out to boot normally. */
// #define SERVO_BENCH_TEST   /* servos validated — off; using TVC_SIGN_CHECK now */
#define SERVO_BENCH_SWEEP_DEG   20    /* +/- degrees from home */
#define SERVO_BENCH_PAUSE_MS    1500  /* hold time at each end */
/* =========================================================================== */

/* ---------------------------------------------------------------------------
   !!! MEASURE THIS. Do not trust the schematic.
   !!! With the 3S LiFePO4 connected: DMM across the pack (V_pack) and at the
   !!! ADC pin (V_pin), then VBAT_DIV_K = V_pack / V_pin.
   !!! The old 4.13 reported 7.89 V for a pack that should sit near 9.9 V.
   --------------------------------------------------------------------------- */
#define VBAT_DIV_K   4.87f
#define VBAT_LP_ALPHA 0.05f   /* the pack sags hard under servo/LoRa current pulses */


#define LSM6DSO_I2C_ADDR (0x6A << 1)
/* USER CODE END PD */

ADC_HandleTypeDef hadc1;
DMA_HandleTypeDef hdma_adc1;

CRC_HandleTypeDef hcrc;

I2C_HandleTypeDef hi2c1;
I2C_HandleTypeDef hi2c2;
I2C_HandleTypeDef hi2c3;

RNG_HandleTypeDef hrng;

RTC_HandleTypeDef hrtc;

SPI_HandleTypeDef hspi1;
SPI_HandleTypeDef hspi2;
SPI_HandleTypeDef hspi3;
DMA_HandleTypeDef hdma_spi2_rx;
DMA_HandleTypeDef hdma_spi2_tx;

TIM_HandleTypeDef htim2;
TIM_HandleTypeDef htim4;
TIM_HandleTypeDef htim5;
TIM_HandleTypeDef htim6;
TIM_HandleTypeDef htim7;
DMA_HandleTypeDef hdma_tim2_ch2_ch4;

UART_HandleTypeDef huart1;
DMA_HandleTypeDef hdma_usart1_rx;

/* USER CODE BEGIN PV */
TIM_HandleTypeDef htim3;          /* 400 Hz control loop */
LSM6DSO_Object_t hlsm6dso1;
LSM6DSO_IO_t lsm6dso_io;

// GNSS_StateHandle GNSS_Handle;

BMP388_HandleTypeDef hbmp388;

EE24_HandleTypeDef h24lc64;

Buzzer_Handle hbuzz1;

servo_t hservo1, hservo2, hservo3, hservo4, hservo5, hservo6;
gngga_t gps;

FATFS fs;

float battery_v;
uint32_t adc_buff[1];

bool buzz_state;

uint8_t lora_buf[255];
uint8_t received_len;

uint8_t gps_working_buf[1024];

extern bool POST_fault_flags[];

uint32_t FreeSpace;
FATFS FatFs;
// extern SX1262 SX_stc;
uint32_t flight_rand_id;
/* USER CODE END PV */

void SystemClock_Config(void);
static void MX_GPIO_Init(void);
static void MX_DMA_Init(void);
static void MX_ADC1_Init(void);
static void MX_I2C1_Init(void);
static void MX_I2C2_Init(void);
static void MX_I2C3_Init(void);
static void MX_RTC_Init(void);
static void MX_SPI1_Init(void);
static void MX_SPI2_Init(void);
static void MX_SPI3_Init(void);
static void MX_TIM4_Init(void);
static void MX_TIM5_Init(void);
static void MX_USART1_UART_Init(void);
static void MX_CRC_Init(void);
static void MX_TIM7_Init(void);
static void MX_TIM2_Init(void);
static void MX_TIM6_Init(void);
static void MX_RNG_Init(void);
/* USER CODE BEGIN PFP */
#ifdef SERVO_BENCH_TEST
void Servo_BenchTest(void);
#endif
void Ctrl_Timer_Init(void);
void Ctrl_Timer_Start(void);
void Ctrl_Timer_Stop(void);
void Get_Vbat(void);
void platform_delay(uint32_t ms);

int32_t platform_imu_init(void);
int32_t platform_imu_deinit(void);
int32_t platform_imu_read(uint16_t Address, uint16_t Reg, uint8_t *Data, uint16_t Length);
int32_t platform_imu_write(uint16_t Address, uint16_t Reg, uint8_t *Data, uint16_t Length);
int32_t platform_get_tick(void);
/* USER CODE END PFP */

/* USER CODE BEGIN 0 */
void PRS_Init(void){
  hbmp388.hi2c = &hi2c2;
  uint32_t rprs, rtemp, time;
  if(BMP388_Init(&hbmp388) == HAL_OK){
    HAL_Delay(5);
    BMP388_SetTempOS(&hbmp388, BMP388_OVERSAMPLING_8X);
    BMP388_SetPressOS(&hbmp388, BMP388_OVERSAMPLING_8X);
    BMP388_SetIIRFilterCoeff(&hbmp388, BMP3_IIR_FILTER_COEFF_3);
    BMP388_SetOutputDataRate(&hbmp388, BMP3_ODR_50_HZ);
    BMP388_ReadRawPressTempTime(&hbmp388, &rprs, &rtemp, &time);  // DUMMY
  }else{
    POST_fault_flags[PRS_Comm_Fail] = 1;
  }
}

void IMU_Init(void){
  lsm6dso_io.BusType  = LSM6DSO_SPI_4WIRES_BUS;
  lsm6dso_io.Address  = 0;
  lsm6dso_io.Init     = platform_imu_init;
  lsm6dso_io.DeInit   = platform_imu_deinit;
  lsm6dso_io.ReadReg  = platform_imu_read;
  lsm6dso_io.WriteReg = platform_imu_write;
  lsm6dso_io.GetTick  = platform_get_tick;
  lsm6dso_io.Delay    = platform_delay;

  if (LSM6DSO_RegisterBusIO(&hlsm6dso1, &lsm6dso_io) == LSM6DSO_OK){
    if (LSM6DSO_Init(&hlsm6dso1) == LSM6DSO_OK){
      IMU_Fusion_Init(&hlsm6dso1);
      HAL_Delay(100);
      // IMU_Fusion_CalibrateGyro(200);
    }
  }else{
    POST_fault_flags[IMU_Comm_Fail] = 1;
  }
}

void LoRa_Init(void){
  SX1262_Get_st()->SPI = hspi3;
  SX1262_Get_st()->Reset_Port = LORA_NRST_GPIO_Port;
  SX1262_Get_st()->Reset_Pin = LORA_NRST_Pin;
  SX1262_Get_st()->NSS_Port = LORA_NSS_GPIO_Port;
  SX1262_Get_st()->NSS_Pin = LORA_NSS_Pin;
  SX1262_Get_st()->Busy_Port = LORA_IO0_GPIO_Port;
  SX1262_Get_st()->Busy_Pin = LORA_IO0_Pin;

  if(SX1262_Init() != 0){
    POST_fault_flags[LoRa_Comm_Fail] = 1;
    return;
  }
  SX1262_SetFrequency(433000000);
  SX1262_setModeReceive();
  uint8_t lora_data[] = "Hello, LoRa!";
  SX1262_Transmit(lora_data, sizeof(lora_data));

  /* 17 dbm, BW 250 kHz, CR_4_5, No CRC, SF7, use sync word 0x12 on SX1278*/
}

void FatFs_Test(void){
  FRESULT FR_Status;
  FATFS *FS_Ptr;
  DWORD FreeClusters;

  FR_Status = f_mount(&FatFs, "", 1);
  if (FR_Status == FR_OK){
    f_getfree("", &FreeClusters, &FS_Ptr);
    FreeSpace = (uint32_t)(FreeClusters * FS_Ptr->csize * 0.5);
    if(FreeSpace < MIN_FLASH_SPACE_KB){
      POST_fault_flags[FS_No_Space] = 1;
    }
  }else{
    POST_fault_flags[FS_Not_Found] = 1;
  }

  FR_Status = f_mount(NULL, "", 0);
}

void Servo_Init_All(void){
  Servo_Init(&hservo1, &htim5, TIM_CHANNEL_1);
  Servo_Init(&hservo2, &htim5, TIM_CHANNEL_2);
  Servo_Init(&hservo3, &htim5, TIM_CHANNEL_3);

  /* TVC servos = KST X10 Mini Pro-A: 900..2100 us -> -60..+60 deg (1500 us =
     center). Map software 0..120 deg to that range, so 1 software deg = 1 servo
     deg and 60 deg = mechanical center. Restrict the us limits here if you want
     less travel. hservo3 (parachute) is left on its default map, so its deploy
     pulse is unchanged. */
  Servo_SetLimitsUS(&hservo1, 0.0f, 120.0f, 900, 2100);
  Servo_SetLimitsUS(&hservo2, 0.0f, 120.0f, 900, 2100);

  Servo_SetAngle(&hservo1, Servo1_Home);
  Servo_SetAngle(&hservo2, Servo2_Home);
  Servo_SetAngle(&hservo3, Parachute_Servo_Home);
}

void GPS_Init(void){
  HAL_UART_Receive_DMA(&huart1, gps_working_buf, sizeof(gps_working_buf));
  __HAL_UART_ENABLE_IT(&huart1, UART_IT_IDLE);
}

void EEPROM_Init(void){
  if(EE24_Init(&h24lc64, &hi2c1, EE24_ADDRESS_DEFAULT, EEP_WP_GPIO_Port, EEP_WP_Pin) != 1){
    POST_fault_flags[EEPROM_Comm_Fail] = 1;
  }
}

void LoRa_TxTelemetry(void){
  // uint8_t telem_buf[19];
  // Mission_BuildTelemetryPacket(telem_buf);
  // SX1262_Transmit(telem_buf, sizeof(telem_buf));

  uint8_t raw_telem_buf[54];
  Mission_BuildRAWTelemetryPacket(raw_telem_buf);
  SX1262_Transmit(raw_telem_buf, sizeof(raw_telem_buf));
}
/* USER CODE END 0 */

/**
  * @brief  The application entry point.
  * @retval int
  */
int main(void)
{

  /* MCU Configuration--------------------------------------------------------*/

  /* Reset of all peripherals, Initializes the Flash interface and the Systick. */
  HAL_Init();

  /* Configure the system clock */
  SystemClock_Config();

  /* Initialize all configured peripherals */
  MX_GPIO_Init();
  MX_DMA_Init();
  MX_ADC1_Init();
  MX_I2C1_Init();
  MX_I2C2_Init();
  MX_I2C3_Init();
  MX_RTC_Init();
  MX_SPI1_Init();
  MX_SPI2_Init();
  MX_SPI3_Init();
  MX_TIM4_Init();
  MX_TIM5_Init();
  MX_USART1_UART_Init();
  MX_USB_DEVICE_Init();
  MX_CRC_Init();
  MX_FATFS_Init();
  MX_TIM7_Init();
  MX_TIM2_Init();
  MX_TIM6_Init();
  MX_RNG_Init();
  /* USER CODE BEGIN 2 */
  BUZZ(&hbuzz1, 300);

  LED_Set_Color(64, 64, 0);

  EEPROM_Init();
  GPS_Init();
  PRS_Init();
  IMU_Init();
  LoRa_Init();
  Servo_Init_All();
#ifdef SERVO_BENCH_TEST
  /* Bench servo check — never returns. Comment out SERVO_BENCH_TEST (top of
     file) to boot normally into the mission. */
  Servo_BenchTest();
#endif
  FatFs_Test();

  HAL_RNG_GenerateRandomNumber(&hrng, &flight_rand_id);

  Mission_Init();

  /* Configured now, started later by Mission_StartControlLoop() -- gyro bias
     calibration must have SPI2 to itself first. */
  Ctrl_Timer_Init();

  LED_Set_Color(0, 64, 0);

  BUZZ(&hbuzz1, 300);

  uint32_t tel_tmr = HAL_GetTick();
  /* USER CODE END 2 */

  /* Infinite loop */
  /* USER CODE BEGIN WHILE */
  while (1)
  {
    // if(gps.lat != 0 && gps.valid){
    //   BUZZ(&hbuzz1, 300);
    // }
    if(HAL_GetTick() - tel_tmr > 100){
      LoRa_TxTelemetry();
      tel_tmr = HAL_GetTick();
    }

    Mission_Update();

    Get_Vbat();
    /* USER CODE END WHILE */

    /* USER CODE BEGIN 3 */
  }
  /* USER CODE END 3 */
}

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
/* USER CODE BEGIN 4 */

/* Bench servo test — see the SERVO_BENCH_TEST block near the top of the file.
   Sweeps one TVC servo at a time between home+SWEEP and home-SWEEP, pausing at
   each end. Loops forever; power the board off when done. Uses SetAngleFine so
   it exercises the exact actuation path (and per-servo KST calibration) that TVC
   uses in flight. */
#ifdef SERVO_BENCH_TEST
static void Servo_BenchTest_One(servo_t *servo, float home)
{
    /* start centred so you can see the reference point */
    Servo_SetAngleFine(servo, home);
    HAL_Delay(SERVO_BENCH_PAUSE_MS);

    for (int i = 0; i < 3; i++)          /* a few cycles so it's easy to watch */
    {
        Servo_SetAngleFine(servo, home + SERVO_BENCH_SWEEP_DEG);   /* one end  */
        HAL_Delay(SERVO_BENCH_PAUSE_MS);
        Servo_SetAngleFine(servo, home - SERVO_BENCH_SWEEP_DEG);   /* other end*/
        HAL_Delay(SERVO_BENCH_PAUSE_MS);
    }

    Servo_SetAngleFine(servo, home);     /* leave it centred before next servo */
    HAL_Delay(SERVO_BENCH_PAUSE_MS);
}

void Servo_BenchTest(void)
{
    while (1)
    {
        /* Servo 1, on its own */
        LED_Set_Color(64, 0, 0);         /* red while servo 1 sweeps */
        Servo_BenchTest_One(&hservo1, (float)Servo1_Home);

        /* Servo 2, on its own */
        LED_Set_Color(0, 0, 64);         /* blue while servo 2 sweeps */
        Servo_BenchTest_One(&hservo2, (float)Servo2_Home);
    }
}
#endif /* SERVO_BENCH_TEST */

/* USER CODE END 4 */

void Get_Vbat(void){
  HAL_ADC_Start_DMA(&hadc1, adc_buff, 1);
}

void HAL_SPI_TxRxCpltCallback(SPI_HandleTypeDef *hspi){
  if(hspi == &hspi3){
	  HAL_SPI_Receive_IT(&hspi3,(uint8_t *)lora_buf,5);
  }
}

volatile uint32_t inttime;
void HAL_GPIO_EXTI_Callback(uint16_t GPIO_Pin){
  if(GPIO_Pin == LORA_DIO1_Pin){
    BUZZ(&hbuzz1, 100);
  }
  /* IMU_INT1 / DRDY is deliberately NOT handled any more. It used to fire at
     3333 Hz and do blocking SPI2 reads from interrupt context while the main
     loop was mid-transaction on the same bus. The IMU is now read from
     Mission_ControlTick() only. */
}

void HAL_ADC_ConvCpltCallback(ADC_HandleTypeDef *hadc){
  if(hadc->Instance == ADC1){
    /* 12-bit full scale is 4096, not 4095. And filter it: a single instantaneous
       sample lands wherever the pack happens to be during a servo or LoRa TX
       current spike. */
    float v = ((float)(adc_buff[0] & 0x0FFF) * 3.3f / 4096.0f) * VBAT_DIV_K;

    if (battery_v <= 0.0f) battery_v = v;                       /* first sample */
    else battery_v += VBAT_LP_ALPHA * (v - battery_v);
  }
}

// void HAL_UART_RxCpltCallback(UART_HandleTypeDef *huart){
//   if (huart->Instance == USART1){
//     if (huart->RxEventType == HAL_UART_RXEVENT_TC){
//       GPS_Process_Data(gps_working_buf, sizeof(gps_working_buf));

//       HAL_UART_Receive_DMA(&huart1, gps_working_buf, sizeof(gps_working_buf));
//     }
//   }
// }

int32_t platform_imu_init(void){
  return 0;
}

int32_t platform_imu_deinit(void){
  return 0;
}

int32_t platform_imu_write(uint16_t Address, uint16_t Reg, uint8_t *Data, uint16_t Length){
  (void)Address;

  uint8_t buf[256];
  if (Length + 1 > sizeof(buf)) return -1;

  buf[0] = ((uint8_t)Reg) & 0x7F;
  memcpy(&buf[1], Data, Length);

  IMU_NSS_GPIO_Port->BSRR = IMU_NSS_Pin << 16; // Set NSS low

  if (HAL_SPI_Transmit_DMA(&hspi2, buf, Length + 1) != HAL_OK){
    IMU_NSS_GPIO_Port->BSRR = IMU_NSS_Pin; // Set NSS high
    return -1;
  }
  // IMU_NSS_GPIO_Port->BSRR = IMU_NSS_Pin; // Set NSS high

  return 0;
}

int32_t platform_imu_read(uint16_t Address, uint16_t Reg, uint8_t *Data, uint16_t Length){
    (void)Address;

    uint8_t tx_buf[1 + Length];
    uint8_t rx_buf[1 + Length];

    memset(tx_buf, 0xFF, sizeof(tx_buf));

    tx_buf[0] = ((uint8_t)Reg) | 0x80; // Read bit set

    IMU_NSS_GPIO_Port->BSRR = IMU_NSS_Pin << 16; // NSS low

    if (HAL_SPI_TransmitReceive(&hspi2, tx_buf, rx_buf, 1 + Length, HAL_MAX_DELAY) != HAL_OK) {
        IMU_NSS_GPIO_Port->BSRR = IMU_NSS_Pin; // NSS high
        return -1;
    }

    IMU_NSS_GPIO_Port->BSRR = IMU_NSS_Pin; // NSS high

    memcpy(Data, &rx_buf[1], Length);

    return 0;
}

int32_t platform_get_tick(void){
  return (int32_t)HAL_GetTick();
}

void platform_delay(uint32_t ms){
    HAL_Delay(ms);
}

void HAL_TIM_PeriodElapsedCallback(TIM_HandleTypeDef *htim){
  if (htim == &htim7){
    HAL_GPIO_TogglePin(BUZZER_GPIO_Port, BUZZER_Pin);
    hbuzz1.ticks--;
    if(hbuzz1.ticks == 0){
      HAL_GPIO_WritePin(BUZZER_GPIO_Port, BUZZER_Pin, GPIO_PIN_RESET);
      HAL_TIM_Base_Stop(&htim7);
    }
  }else if(htim == &htim6){
    Mission_IncTick();
  }else if(htim == &htim3){
    Mission_ControlTick();
  }
}

void HAL_SPI_TxCpltCallback(SPI_HandleTypeDef *hspi){
  if (hspi == &hspi2){
    // Wait until SPI fully finished
    while (hspi->Instance->SR & SPI_SR_BSY);

    // Now it's safe to release NSS
    IMU_NSS_GPIO_Port->BSRR = IMU_NSS_Pin;
  }
}

/* ---------------------------------------------------------------------------
   400 Hz control loop timer (TIM3).

   TIM3 is on APB1. With SYSCLK = 144 MHz and APB1 = /4, the APB1 TIMER clock is
   72 MHz (same as TIM6, which uses prescaler 72-1 for its 1 us tick).

     72 MHz / 72 = 1 MHz;  1 MHz / 2500 = 400 Hz
   --------------------------------------------------------------------------- */
void Ctrl_Timer_Init(void)
{
  __HAL_RCC_TIM3_CLK_ENABLE();

  htim3.Instance               = TIM3;
  htim3.Init.Prescaler         = 72 - 1;      /* -> 1 MHz  */
  htim3.Init.CounterMode       = TIM_COUNTERMODE_UP;
  htim3.Init.Period            = 2500 - 1;    /* -> 400 Hz */
  htim3.Init.ClockDivision     = TIM_CLOCKDIVISION_DIV1;
  htim3.Init.AutoReloadPreload = TIM_AUTORELOAD_PRELOAD_DISABLE;

  if (HAL_TIM_Base_Init(&htim3) != HAL_OK)
  {
    Error_Handler();
  }

  /* Above the SD/LoRa/GPS work in the main loop, but leave room for anything
     that must pre-empt it. The ISR does two short SPI2 reads (~25 us at 9 MHz). */
  HAL_NVIC_SetPriority(TIM3_IRQn, 5, 0);
  HAL_NVIC_EnableIRQ(TIM3_IRQn);
}

void Ctrl_Timer_Start(void)
{
  __HAL_TIM_SET_COUNTER(&htim3, 0);
  HAL_TIM_Base_Start_IT(&htim3);
}

void Ctrl_Timer_Stop(void)
{
  HAL_TIM_Base_Stop_IT(&htim3);
}

void TIM3_IRQHandler(void)
{
  HAL_TIM_IRQHandler(&htim3);
}

/* USER CODE END 4 */
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


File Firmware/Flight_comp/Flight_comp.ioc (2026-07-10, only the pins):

Mcu.UserName=STM32F405RGTx
PA0-WKUP.GPIO_Label=SERVO1
PA0-WKUP.Signal=S_TIM5_CH1
PA1.GPIO_Label=SERVO2
PA1.Signal=S_TIM5_CH2
PA10.GPIO_Label=GPS_RX
PA10.Signal=USART1_RX
PA11.Signal=USB_OTG_FS_DM
PA12.Signal=USB_OTG_FS_DP
PA13.Signal=SYS_JTMS-SWDIO
PA14.Signal=SYS_JTCK-SWCLK
PA15.GPIO_Label=LORA_NSS
PA15.Signal=GPIO_Output
PA2.GPIO_Label=SERVO3
PA2.Signal=S_TIM5_CH3
PA3.GPIO_Label=SERVO4
PA3.Signal=S_TIM5_CH4
PA4.GPIO_Label=BAT_VSENCE
PA4.Signal=ADCx_IN4
PA5.GPIO_Label=FLASH_SCK
PA5.Signal=SPI1_SCK
PA6.GPIO_Label=FLASH_MISO
PA6.Signal=SPI1_MISO
PA7.GPIO_Label=FLASH_MOSI
PA7.Signal=SPI1_MOSI
PA8.GPIO_Label=GPS_SCL
PA8.Signal=I2C3_SCL
PA9.GPIO_Label=GPS_TX
PA9.Signal=USART1_TX
PB0.GPIO_Label=LORA_DIO1
PB0.Signal=GPXTI0
PB1.GPIO_Label=LORA_IO0
PB1.Signal=GPIO_Input
PB10.GPIO_Label=BMP_SCL
PB10.Signal=I2C2_SCL
PB11.GPIO_Label=BMP_SDA
PB11.Signal=I2C2_SDA
PB12.GPIO_Label=IMU_NSS
PB12.Signal=GPIO_Output
PB13.GPIO_Label=IMU_SCK
PB13.Signal=SPI2_SCK
PB14.GPIO_Label=IMU_MISO
PB14.Signal=SPI2_MISO
PB15.GPIO_Label=IMU_MOSI
PB15.Signal=SPI2_MOSI
PB2.GPIO_Label=BMP_INT
PB2.Signal=GPXTI2
PB3.GPIO_Label=LED
PB3.Signal=S_TIM2_CH2
PB4.Signal=GPIO_Analog
PB5.GPIO_Label=EEP_WP
PB5.Signal=GPIO_Output
PB6.GPIO_Label=EEP_SCL
PB6.Signal=I2C1_SCL
PB7.GPIO_Label=EEP_SDA
PB7.Signal=I2C1_SDA
PB8.GPIO_Label=SERVO5
PB8.Signal=S_TIM4_CH3
PB9.GPIO_Label=SERVO6
PB9.Signal=S_TIM4_CH4
PC0.GPIO_Label=CAM_CTRL
PC0.Signal=GPIO_Output
PC10.GPIO_Label=LORA_SCK
PC10.Signal=SPI3_SCK
PC11.GPIO_Label=LORA-MISO
PC11.Signal=SPI3_MISO
PC12.GPIO_Label=LORA_MOSI
PC12.Signal=SPI3_MOSI
PC14-OSC32_IN.Signal=RCC_OSC32_IN
PC15-OSC32_OUT.Signal=RCC_OSC32_OUT
PC3.GPIO_Label=BUZZER
PC3.Signal=GPIO_Output
PC4.GPIO_Label=FLASH_NSS
PC4.Signal=GPIO_Output
PC5.GPIO_Label=FLASH_WP
PC5.Signal=GPIO_Output
PC6.GPIO_Label=IMU_INT1
PC6.Signal=GPXTI6
PC7.GPIO_Label=PYRO1
PC7.Signal=GPIO_Output
PC8.GPIO_Label=PYRO2
PC8.Signal=GPIO_Output
PC9.GPIO_Label=GPS_SDA
PC9.Signal=I2C3_SDA
PD2.GPIO_Label=LORA_NRST
PD2.Signal=GPIO_Output
PH0-OSC_IN.Signal=RCC_OSC_IN
PH1-OSC_OUT.Signal=RCC_OSC_OUT

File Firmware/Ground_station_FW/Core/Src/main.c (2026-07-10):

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
/* Includes ------------------------------------------------------------------*/
#include "main.h"
#include "usb_device.h"

/* USER CODE BEGIN Includes */
#include "SX1278.h"
#include "usbd_cdc_if.h"
#include "stdint.h"
/* USER CODE END Includes */

/* USER CODE BEGIN PTD */
typedef struct __attribute__((packed)) {
    float altitude;           // 4 bytes
    int16_t accel;            // 2 bytes (cm/s^2)
    int16_t speed;            // 2 bytes (cm/s)
    int16_t pitch, roll, yaw; // 6 bytes (DEG*10)
    uint8_t flight_state;     // 1 byte
    uint32_t timestamp;       // 4 bytes
    int8_t RSSI;              // 1 byte (locally calculated)
} TelemetryData_t; // Total: 20 bytes (MAX for BLE packet is 20 bytes)
/* USER CODE END PTD */

IPCC_HandleTypeDef hipcc;

RTC_HandleTypeDef hrtc;

SPI_HandleTypeDef hspi1;

/* USER CODE BEGIN PV */
SX1278_hw_t SX1278_hw;
SX1278_t SX1278;

int master;
int ret;

char buffer[512];

int message;
int message_length;
/* USER CODE END PV */

void SystemClock_Config(void);
void PeriphCommonClock_Config(void);
static void MX_GPIO_Init(void);
static void MX_IPCC_Init(void);
static void MX_RTC_Init(void);
static void MX_SPI1_Init(void);
static void MX_RF_Init(void);
/**
  * @brief  The application entry point.
  * @retval int
  */
int main(void)
{

  /* MCU Configuration--------------------------------------------------------*/

  /* Reset of all peripherals, Initializes the Flash interface and the Systick. */
  HAL_Init();
  /* Config code for STM32_WPAN (HSE Tuning must be done before system clock configuration) */
  MX_APPE_Config();

  /* Configure the system clock */
  SystemClock_Config();

  /* Configure the peripherals common clocks */
  PeriphCommonClock_Config();

  /* IPCC initialisation */
  MX_IPCC_Init();

  /* USER CODE BEGIN SysInit */
  LL_HSEM_1StepLock(HSEM, 5 );
  /* USER CODE END SysInit */

  /* Initialize all configured peripherals */
  MX_GPIO_Init();
  MX_RTC_Init();
  MX_SPI1_Init();
  MX_USB_Device_Init();
  MX_RF_Init();
  /* USER CODE BEGIN 2 */
  SX1278_hw.dio0.port = SPI1_G0_GPIO_Port;
	SX1278_hw.dio0.pin = SPI1_G0_Pin;
	SX1278_hw.nss.port = SPI1_NSS_GPIO_Port;
	SX1278_hw.nss.pin = SPI1_NSS_Pin;
	SX1278_hw.reset.port = SPI1_RST_GPIO_Port;
	SX1278_hw.reset.pin = SPI1_RST_Pin;
	SX1278_hw.spi = &hspi1;

	SX1278.hw = &SX1278_hw;
	
	SX1278_init(&SX1278, 433000000, SX1278_POWER_17DBM, SX1278_LORA_SF_7,
	SX1278_LORA_BW_250KHZ, SX1278_LORA_CR_4_5, SX1278_LORA_CRC_DIS, 10);

  ret = SX1278_LoRaEntryRx(&SX1278, 16, 2000);
  HAL_GPIO_WritePin(LED_GPIO_Port, LED_Pin, ret);

  /* USER CODE END 2 */

  /* Init code for STM32_WPAN */
  MX_APPE_Init();

  /* Infinite loop */
  /* USER CODE BEGIN WHILE */
  while (1)
  {
    if (message) {
      ret = SX1278_LoRaRxPacket(&SX1278);
			if (ret > 0) {
				SX1278_read(&SX1278, (uint8_t*) buffer, ret);
        HAL_GPIO_TogglePin(LED_GPIO_Port, LED_Pin);

        // buffer[19] = SX1278_RSSI(&SX1278); // Append RSSI to the end of the buffer

        char hex_log[256]; // (21 bytes * 2 chars) + 2 for \r\n + 1 for null = 45
        int pos = 0;
        uint8_t *byte_ptr = (uint8_t *)&buffer;

        for (int i = 0; i < ret; i++) {
            pos += sprintf(&hex_log[pos], "%02X ", byte_ptr[i]);
        }
        sprintf(&hex_log[pos], "\r\n");

        CDC_Transmit_FS((uint8_t*) hex_log, strlen(hex_log));
			}
    }
    /* USER CODE END WHILE */
    MX_APPE_Process();

    /* USER CODE BEGIN 3 */
  }
  /* USER CODE END 3 */
}

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
/* USER CODE BEGIN 4 */
void HAL_GPIO_EXTI_Callback(uint16_t GPIO_Pin) {
  if (GPIO_Pin == SPI1_G0_Pin) {
    message = 1;
  }
}
/* USER CODE END 4 */
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


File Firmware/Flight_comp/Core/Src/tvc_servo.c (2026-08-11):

#include "tvc_servo.h"
#include <stddef.h>   /* NULL */
#include <math.h>     /* isfinite, sinf, cosf */

/* =========================================================================
   Internal helpers
   ========================================================================= */

/*
 * clampf – symmetric float clamp.
 */
static float clampf(float value, float limit)
{
    if (value >  limit) return  limit;
    if (value < -limit) return -limit;
    return value;
}

/*
 * pid_init – initialise a single-axis PID.
 */
static void pid_init(TVC_PID_t *pid, float Kp, float Ki, float Kd, float i_limit)
{
    pid->Kp          = Kp;
    pid->Ki          = Ki;
    pid->Kd          = Kd;
    pid->integrator  = 0.0f;
    pid->i_limit     = i_limit;
    pid->output      = 0.0f;
}

/*
 * pid_reset – zero integrator and output without touching gains.
 */
static void pid_reset(TVC_PID_t *pid)
{
    pid->integrator = 0.0f;
    pid->output     = 0.0f;
}

/*
 * pid_step – compute one PID step.
 *
 * error   – angle error in degrees  (setpoint is 0 = vertical)
 * rate    – angular rate in milli-DPS (positive = tilting in positive direction)
 * dt_s    – timestep in seconds (already clamped by TVC_Update caller)
 *
 * Returns the signed deflection command in degrees.
 *
 * Sign convention:
 *   Positive angle error (rocket tilted forward/right) →
 *   Positive output → servo deflects nozzle to correct back toward vertical.
 *   The calling code adds this to the home angle; a positive output means
 *   "deflect the nozzle in the direction that produces a corrective torque."
 *   Physical verification of sign is done during benchtop testing by
 *   confirming the nozzle deflects in the corrective direction.
 *
 * D term:
 *   Kd * rate_mdps
 *   We use the measured angular rate directly instead of differentiating
 *   the angle. This is equivalent but avoids amplifying angle measurement
 *   noise. The milli-DPS unit is absorbed by Kd (a typical Kd will be on
 *   the order of 0.001–0.01 for milli-DPS input).
 */
static float pid_step(TVC_PID_t *pid, float error, float rate_mdps, float dt_s)
{
    /* --- P term --- */
    float p_term = pid->Kp * error;

    /* --- I term: integrate error, then clamp --- */
    pid->integrator += error * dt_s;
    pid->integrator  = clampf(pid->integrator, pid->i_limit);
    float i_term     = pid->Ki * pid->integrator;

    /* --- D term: rate feedback directly from gyro ---
       NOTE: the caller passes the NEGATED rate, because d(error)/dt = -rate
       (the setpoint is a constant 0). The old code passed +rate, which made
       the D term positive feedback on angular rate -- it accelerated the
       divergence instead of damping it. */
    float d_term = pid->Kd * rate_mdps;

    /* --- Sum and clamp to mechanical travel limit --- */
    float raw_output = p_term + i_term + d_term;
    float clamped    = clampf(raw_output, TVC_MAX_DEFLECTION_DEG);

    pid->output = clamped;
    return clamped;
}

/* =========================================================================
   Public API
   ========================================================================= */

void TVC_Init(TVC_t    *tvc,
              servo_t  *pitch_servo,
              servo_t  *yaw_servo,
              float     pitch_home,
              float     yaw_home,
              float     Kp,
              float     Ki,
              float     Kd,
              float     i_limit)
{
    if (tvc == NULL) return;

    tvc->pitch_servo = pitch_servo;
    tvc->yaw_servo   = yaw_servo;
    tvc->pitch_home  = pitch_home;
    tvc->yaw_home    = yaw_home;
    tvc->enabled     = false;

    pid_init(&tvc->pitch, Kp, Ki, Kd, i_limit);
    pid_init(&tvc->yaw,   Kp, Ki, Kd, i_limit);
}

void TVC_SetGains(TVC_t *tvc, uint8_t axis, float Kp, float Ki, float Kd)
{
    if (tvc == NULL) return;

    TVC_PID_t *pid = (axis == 0) ? &tvc->pitch : &tvc->yaw;

    pid->Kp = Kp;
    pid->Ki = Ki;
    pid->Kd = Kd;
    /* Integrator and i_limit are intentionally not touched here so that
       live gain changes during a test don't reset accumulated state. */
}

void TVC_Enable(TVC_t *tvc)
{
    if (tvc == NULL) return;
    tvc->enabled = true;
}

void TVC_Disable(TVC_t *tvc)
{
    if (tvc == NULL) return;

    tvc->enabled = false;

    /* Park servos at home */
    if (tvc->pitch_servo != NULL)
        Servo_SetAngleFine(tvc->pitch_servo, tvc->pitch_home);

    if (tvc->yaw_servo != NULL)
        Servo_SetAngleFine(tvc->yaw_servo, tvc->yaw_home);
}

void TVC_Reset(TVC_t *tvc)
{
    if (tvc == NULL) return;
    pid_reset(&tvc->pitch);
    pid_reset(&tvc->yaw);
}

void TVC_Update(TVC_t *tvc,
                float  pitch_angle,
                float  pitch_rate_mdps,
                float  yaw_angle,
                float  yaw_rate_mdps,
                float  dt_s)
{
    if (tvc == NULL) return;

    /* --- Guard dt --- */
    if (dt_s < 0.0001f) dt_s = 0.0001f;
    if (dt_s > 0.1f)    dt_s = 0.1f;

    if (!tvc->enabled)
    {
        /* Keep servos at home, reset integrators */
        pid_reset(&tvc->pitch);
        pid_reset(&tvc->yaw);

        if (tvc->pitch_servo != NULL)
            Servo_SetAngleFine(tvc->pitch_servo, tvc->pitch_home);

        if (tvc->yaw_servo != NULL)
            Servo_SetAngleFine(tvc->yaw_servo, tvc->yaw_home);

        return;
    }

    /* ------------------------------------------------------------------
       Run PID for each axis.

       The setpoint is 0 degrees (rocket pointing straight up).
       A positive angle means the rocket has tilted in the positive
       direction, so the error fed to the PID is simply the measured angle
       (with a negated sign so the output opposes the tilt — see note below).

       Sign note:
         If the rocket tilts forward (positive pitch angle), the nozzle
         must deflect backward (negative direction in gimbal terms) to
         push the base of the rocket back.  Whether positive PID output
         corresponds to corrective or wrong-direction deflection depends on
         the gimbal wiring and physical mounting.
         The sign of Kp therefore has physical meaning: if the rocket
         oscillates or diverges, flip the sign of all three gains on that
         axis (or equivalently negate the angle and rate inputs).
         Here we use:   error = -angle
         so that positive tilt → negative error → negative output → the
         servo moves in whatever direction reduces the tilt.
         Verify on the bench: tilt the rocket forward and confirm the
         nozzle deflects to push it back.
       ------------------------------------------------------------------ */
    float pitch_error = -pitch_angle;
    float yaw_error   = -yaw_angle;
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

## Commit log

2025-12-03 Sensors added
    [flight_comp.kicad_sch, untitled.kicad_sch]
2026-01-12 Drivers #1
2026-01-27 Drivers #2
2026-01-30 Servo driver
2026-02-01 Debug LED driver
2026-03-13 Ground station mock-up
2026-03-19 added IMU filtering
2026-03-20 test files and docker added
    [test1.csv, test2.csv, test3.csv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]
2026-03-20 Small changes in IMU driver
2026-04-03 GPS antenna connections, pps is connected to the mcu, pps diode replaced
    [flight_comp.kicad_pcb, flight_comp.kicad_sch, sensors.kicad_sch]
2026-04-12 stm32wb55 BLE support for ground station, DMA requests for IMU, LED moved to PB3
    [test1.csv, test2.csv, test3.csv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]
2026-04-14 Testing readded
    [search.csv]
2026-04-14 LoRa and USB for ground station, telemetry package
2026-04-15 Printable altitude telemetry with us timestamps
2026-04-15 Integration of gyro
2026-04-16 gyro integration now in dps instead of mpds
2026-04-20 Status LED now shows faults, added timeout to lora driver
2026-04-21 Servo for TVC
2026-04-30 Quaternion for imy gyro
2026-05-12 sensor filtering added
2026-06-08 pid added
2026-06-08 pid values upadted
2026-07-10 decent and landing detection, telemetry saving
2026-08-04 servo changed to KST

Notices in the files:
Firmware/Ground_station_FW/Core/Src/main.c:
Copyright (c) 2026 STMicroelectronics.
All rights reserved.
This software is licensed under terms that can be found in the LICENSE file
